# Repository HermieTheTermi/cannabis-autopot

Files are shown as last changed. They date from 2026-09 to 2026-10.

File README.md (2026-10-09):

# Smart Grow Topf

Automatisch bewässernder Topf für eine Cannabis-Pflanze, gesteuert über ein **ESP32-C6-Modul direkt auf der eigenen PCB** (eigener 2S-Lader, eigene 5-V-/3,3-V-Wandler), Akkubetrieb. **Eigenes Projekt** (unabhängig vom GrowTower).

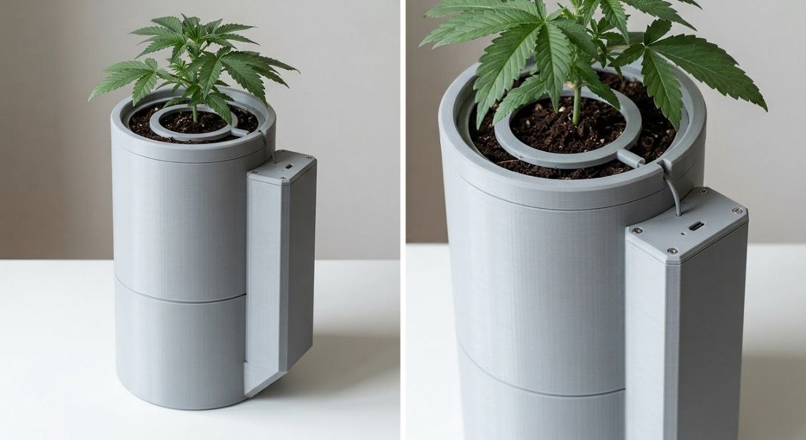
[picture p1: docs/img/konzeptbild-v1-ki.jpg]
Smart Grow Topf – KI-Konzeptbild im Stand V1


*KI-generiertes Konzeptbild (Prompts: [`docs/04_bildkonzepte-prompts.md`](docs/04_bildkonzepte-prompts.md)) — zeigt Wulst mit Deckel und USB-C, Verteilerring auf dem Substrat, Kragen. Keine CAD-Ableitung: verbindliche Maße stehen in [`docs/02_architektur-und-geometrie.md`](docs/02_architektur-und-geometrie.md).*

## Konzept (Top-Drip mit Rücklauf)

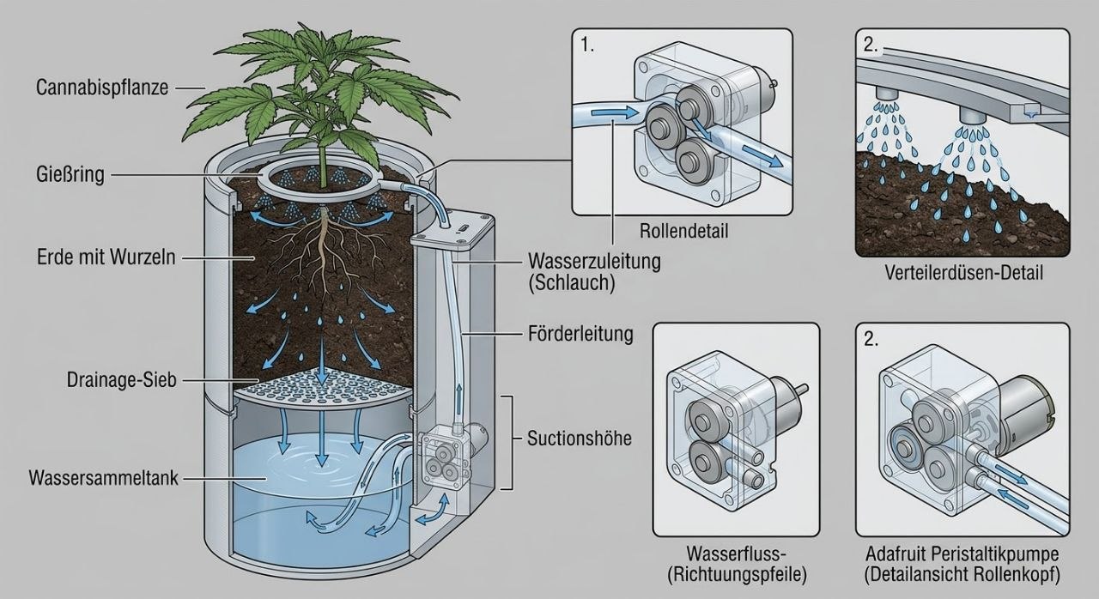
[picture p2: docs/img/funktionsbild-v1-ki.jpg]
Funktionsbild Smart Grow Topf – Weg des Wassers im Schnitt


*KI-generiertes Funktionsbild (Prompt 3 aus [`docs/04_bildkonzepte-prompts.md`](docs/04_bildkonzepte-prompts.md)) — Weg des Wassers: Peristaltikpumpe in der Wulst → Druckleitung über den Kragen → Gießring → Tropfen ins Substrat → Drainage-Sieb → zurück in den Sammeltank. Bild und Beschriftung sind KI-generiert und nicht maßhaltig. Was im Bild fehlt: der kapazitive Sensor (bei r ≈ 55 mm, Messebene 75 mm tief) und die 25 mm Blähton-Drainageschicht über dem Sieb; „Suctionshöhe" ist ein KI-Sprachfehler (gemeint: Saughöhe). Verbindlich bleibt [`docs/02_architektur-und-geometrie.md`](docs/02_architektur-und-geometrie.md).*

```
        Verteilerring (3D-Druck)          ← Wasser von oben
   ┌──────────────────────────────┐
   │  ERDE / SUBSTRAT             │   Ø127 innen × 150 mm (≈1,6 L)
   │  ⊗ kapazitiver Sensor        │   Messebene 75 mm = halbe Topfhöhe
   │  ▒▒ Blähton 25 mm ▒▒         │   Dränage + Partikelfilter
   └──────────────┬───────────────┘
        Luftspalt 30 mm (Gießfüße)
   ┌──────────────┴───────────────┐
   │  WASSERTANK 1,0 L            │   Ø134 innen, max. 71 mm Wasserstand
   └──────────────────────────────┘
        Wulst seitlich: Pumpe, PCB (ESP32-C6-Modul), Akku, Schlauch-/Kabelkanal
```

**Gesamthöhe 278 mm**, Grundriss Ø 140 mm (mit Wulst ≈ 180 mm breit).

**Regelkreis:**
1. Kapazitiver Sensor (analog, **invertiert**: trocken = hoher ADC) misst die Substratfeuchte.
2. Zu trocken → **Pumpe EIN** (Peristaltik, Wasser von oben auf den Verteilerring).
3. Überschuss läuft durchs Substrat und zurück in den Tank.
4. **10–20 min** später erneut messen: ADC gefallen → ok. ADC nicht gefallen → **Tank leer / Pumpe verstopft** → Telegram-Alarm.

## Warum dieses Design
- **Peristaltik:** Medium bleibt im Schlauch, kommt nie mit der Pumpenmechanik in Kontakt → sauber, kleine Mengen, akkutauglich, selbstansaugend.
- **Top-Drip:** gezielte Dosierung von oben, kein dauerhaft wassergesättigter Topfboden (Luftspalt), Wurzeln bleiben belüftet.
- **Kapazitiver Sensor:** korrosionsfrei, analog direkt am ADC, Messebene in der Wurzelzone.
- **Wulst statt Innenraum:** Elektronik komplett über dem Wasserstand, Sensor/Kabel/Schlauch sauber geführt.

## Projektstruktur
```
cannabis-autopot/
├── README.md
├── docs/
│   ├── 01_anforderungen.md              ← Festlegungen des Users
│   ├── 02_architektur-und-geometrie.md  ← verbindliche Maße (CAD/PCB-Grundlage)
│   ├── 04_bildkonzepte-prompts.md       ← KI-Image-Prompts (+ generierte .txt)
│   ├── 13_bildprompts-endstand.md       ← 3 deutsche Prompts für den fertigen Topf (inkl. Sprudler)
│   ├── 14_platinengroesse.md            ← Bauteilfläche + Boardgrößen-Rechnung (54 mm / frei)
│   └── img/                             ← KI-Konzeptbilder
├── scripts/
│   ├── check_netlist.py                 ← Lint der Netzliste (exit 0 vor dem Layout nötig)
│   ├── bauteilflaeche.py                ← Footprint-Flächen + Platinengröße (EasyEDA-API)
│   └── check_bom_consistency.py         ← Querabgleich Schaltplan ↔ JLCPCB-BOM
├── hardware/
│   ├── design/                          ← Schaltplan als Python-Modell: 29 Prüfungen + Simulationen
│   │   └── MUTATIONSTEST.md             ← Nachweis, dass jede Prüfung bei Fehlern anschlägt
│   ├── bom_entscheidung.md              ← BESTELLGRUNDLAGE: Bauteile, Preise, Links
│   ├── schaltplan_v1.md                 ← VERBINDUNGSVORGABE: Netze, Werte, Pinbelegungen
│   ├── schaltplan_v1_netzliste.csv      ← dieselben Verbindungen maschinenlesbar (Netz, Bauteil, Pin)
│   ├── pcba_bom_jlc.csv                 ← BOM im JLCPCB-Upload-Format (LCSC-Codes)
│   ├── pcba_verfuegbarkeit_jlc.md       ← JLC-Verfügbarkeitsprüfung je Position
│   └── hardware_auswahl_bom.md          ← Recherche-/Ideenebene (nicht Bestellgrundlage)
├── research/
│   ├── bom-check/                       ← aktueller Preis-/Verfügbarkeitscheck je Bauteilgruppe
│   ├── kapazitiver-bodenfeuchtesensor-esp32-recherche.md
│   ├── smart-grow-topf_pumpe-bewaesserung.md
│   ├── smart-grow-topf-esp32-firmware-konzept.md
│   ├── markt-konzept-recherche.md
│   ├── markt-vergleich-2026-09.md        ← „Gibt es das schon zu kaufen?“ (17.09.2026)
│   └── fertige-platinen/                 ← „Fertige Platine statt Eigenentwicklung?“ (09.10.2026)
│       ├── 00_verdikt.md                 ← Ergebnis: kein Board deckt alles, Modulweg als Rückfall
│       ├── 01_3d-drucker-mainboards.md   · 02_esp32-boards-akku.md
│       └── 03_power-management-2s.md     · 04_bewaesserungs-controller.md
│   └── bench-board/                      ← Entwicklungs-Board für den Labortisch (09.10.2026)
│       ├── 00_empfehlung.md              ← FireBeetle 2 ESP32-C6 (9,95 €) als Empfehlung + Einkaufsliste
│       ├── 01_steckbaukasten-grove-gravity.md · 02_io-boards-schraubklemmen.md
│       └── 03_mcu-dev-boards-zubehoer.md
└── cad/                                 ← parametrisches Gehäuse-CAD (build123d/Python)
    ├── params.py · lib.py                 ← alle Maße + Helfer
    ├── parts/*.py                         ← ein Modul je Druckteil (build/check)
    ├── assembly.py                        ← Baugruppe über RigidJoints
    └── export_all.py                      ← baut, prüft, exportiert STL + STEP
```

## Status
- [x] Projektordner + Anforderungen + 4 Recherchen (10.09.2026)
- [x] **Entscheidungen 11.09.2026:** Topf Ø140×150 (Erde) + 1 L Tank darunter · ESP32-C6-MINI-1 auf eigener PCB · Wulst mit Kanal · Top-Drip-Ring · Sensor von oben · Telegram final · nur Wasser
- [x] **Höhen-/Volumenberechnung** → Gesamthöhe 278 mm, Tank 1,0 L, Erdvolumen 1,9 L (`docs/02_...`)
- [x] **BOM-Entscheidung** (11.09.2026, Pumpentausch 14.09.2026): ESP32-C6-MINI-1 ≈ 3,60 € · Peristaltikpumpe **CONQUERALL DC 5 V** (Amazon `B0DHVMZ27Y`, ≤150 ml/min, 3 × 5 mm Schlauch) **11,99 €** statt 31,94 € OEM · Sensor v1.2 4,99 € · EFASO-Akku 14,90 € → **≈ 47–49 €** gesamt inkl. Schlauch und Passiven (+ ~28 € JLCPCB-Handling) (`hardware/bom_entscheidung.md`)
- [x] **Versorgung festgelegt (Revision „2S-Umbau\", 16.09.2026):** **2S-Pack 6,0–8,4 V** an J1, **3-polig (B− / Mittelabgriff / B+)** — **Zellschutz (HY2120) und Balancing (IP2326) sitzen auf unserer Platine** · Lader **IP2326** (2S-Boost-Lader aus 5 V USB, 8,4 V / 0,90 A) · **U_BUCK5 SY8113B** → **+5V (5,10 V)** für beide Pumpen und den neuen 5-V-Ausgang J17 · **U_BUCK3 AP63203** → **+3V3 (3,31 V)** für die Logik · Wächter **TPS3839G33** (Auslösung bei 6,16 V Pack). Ersetzt 1S-Akku, MCP73831, ME6211, MAX809 und den MT3608-Boost. ⚠️ **Offen:** der 3-A-Pumpenanlauf liegt zwar am Nennstrom des 5-V-Bucks, aber nur **0,57 A unter dem Isat (4,0 A)** der 4,7-µH-Induktivität → **PWM-Softstart weiter empfohlen**, Messauftrag in `docs/11_review-2s-umbau.md` §8 und `hardware/schaltplan_v1.md` §6.7
- [x] **PCBA geprüft (16.09.2026):** alle Bauteile bei JLCPCB verfügbar (LCSC-Codes in `hardware/pcba_bom_jlc.csv`; **109 bestückte Refs**, davon **17 Extended-Positionen ≈ 51 USD Handling** — `hardware/pcba_verfuegbarkeit_jlc.md` §1b)
- [x] **Sauerstoffpumpe + 5-V-Boost** (15.09.2026): **zweiter** Pumpenpfad — **Q3** (AO3400A) mit
      **R33/R34**, Freilauf **D7**, UV-Klemmzweig **D8**, Stecker **J16** (JST-XH 2P aufrecht, gleicher
      Typ wie J4) an **IO22** (vorher Reserve **J14** ⛔ entfällt). Damit **beide** Pumpen 5 V bekommen,
      erzeugt **U8 MT3608** mit **L1 22 µH**, **D6 SS34**, **C17/C18 22 µF**, **R31 75 kΩ/R32 10 kΩ**
      eine geregelte **+5-V-Schiene (5,10 V)** aus VBAT; J4 Pin 1 und D1 liegen jetzt an **+5V**.
      ⚠️ Zwei Folgepflichten: **PWM-Softstart jetzt Pflicht** (der Boost liefert den 3-A-Anlauf nicht —
      22 µF ≈ 7 µs) und **O2-Pumpe nicht dauerhaft** (1500-mAh-Zelle wäre in ~2,5 h leer).
      Rechnungen + offene Punkte (Platz!, Einbauort außerhalb) in `hardware/schaltplan_v1.md` §10
- [x] **Sauerstoffpumpe ausgewählt** (15.09.2026): **Mini USB Aquarium-Luftpumpe mit Luftstein**,
      Amazon **`B0FXB5BMTT`, 8,48 €** — **5 V USB**, ~1 W (**0,20 A**; aus der Zelle ≈ 0,32 A),
      < 35 dB, für 10–40 L, **Lieferumfang: Pumpe + 1,15 m Silikonschlauch + Luftsprudler**.
      Pumpe am **5-V-Boost** also unkritisch (Boost kann 1 A); Anschluss: USB-Stecker ab, rot/schwarz
      auf **JST-XH 2P (J16)**; Rückschlagventil in die Luftleitung; **außerhalb** des Topfs montieren
      (Membranpumpe braucht Frischluft). Alternativen: `B093GPMT1Z` (9,99 €, 210 L/h),
      `B0B82JX6Z4` (7,29 €, regelbar). Vergleichstabelle + Strom-/Laufzeitrechnung:
      `hardware/bom_entscheidung.md` §8
- [x] **Stecker auf „nach oben" umgestellt** (15.09.2026): J1/J2/J4 von gewinkelt (Side-Entry) auf
      **aufrecht (Top-Entry)** — neue LCSC-Codes `C160352` (Akku PH, SMD), `C493416` (Sensor XH-3P),
      `C158012` (Pumpe XH-2P); vorher `C54582899`/`C157928`/`C157931`. Die aufrechten Typen haben
      deutlich mehr Lager (u. a. J4: 203.889 statt 2). Elektrik unverändert (**Pin-Diff = 0, 50 Netze**),
      PCB per `import-changes` als **„Modify Footprint"** aktualisiert (80 Bauteile, **Platzierung erhalten**)
- [x] **Schaltplan V1 + Netzliste** (`hardware/schaltplan_v1.md`, `..._netzliste.csv`, **68 Netze / 115 Bauteile / 314 Verbindungen / 109 bestückte Positionen**)
- [x] **Design als Python-Modell + Prüfungen** (`hardware/design/`): **29** Design-Regelprüfungen gegen die
      Datenblattgrenzen, 6 Simulationsgruppen, Mutationsabdeckung vollständig (`hardware/design/MUTATIONSTEST.md`)
- [x] **Taster + 3 LEDs** (11.09.2026): externer Nachfüll-Taster an IO6 (weckt aus dem Deep-Sleep), nur
      2 Lötpads auf der Platine · **D5 rot = Tank leer** (IO7, R_TANK 1 kΩ, Firmware blinkt) ·
      **D2 grün = Status** (IO14, C2297, R4 **220 Ω** — grün hat Vf 2,85 V, am 3,3-V-Rail bleiben nur 0,45 V
      Reserve) · D_LEDCHG rot = Ladestatus. Neue Positionen sind **basic** (kein Extended-Aufpreis)
- [x] **Lichtsensor extern + Licht-Gate** (13.09.2026): Bewässerung nur in der Dunkelphase.
      Stecker **J7** (seit 14.09.2026 2,54-mm-Stiftleiste) mit **R_LIGHT 10 kΩ** (offener Stecker
      ⇒ 0 V ⇒ „dunkel", Bewässerung bleibt erlaubt) · **R_LIGHT_S 1 kΩ** + **C_LIGHT 100 nF** am
      ADC · Sensor an **SENSOR_PWR** (geschaltet, keine Standby-Verschlechterung) · ADC auf
      **IO4 (ADC1_CH4)**. Firmware-Fail-safe inkl. Zeitfenster-Fallback und Telegram-Alarm.
      **Pin-Korrektur:** IO4/IO5 sind keine boot-kritischen Strapping-Pins (nur GPIO8/9/15).
- [x] **Pinordnung GND–VCC–SIG** (13.09.2026): alle 3-poligen Stecker auf
      1 = GND · **2 = VCC** · 3 = Signal (nur der mittlere Pin ist gegen Umdrehen invariant — ein
      verkehrt gesteckter Stecker kann so **nie** 3,3 V auf einen MCU-Pin legen). J8 (I²C 4-pol)
      als **GND–VCC_EXT–SDA–SCL**.
- [x] **GPIO-Erweiterung auf 2,54-mm-Stiftleisten** (14.09.2026): alle freien GPIOs + I²C als
      **Stiftleisten (male, gerade)** für Dupont-Buchsen — **je Signal ein eigener 3-pol Stecker**
      (**J9–J15**: IO5/IO15/IO16/IO17/IO21/IO22/IO23), I²C als 4-pol **J8**, Lichtsensor **J7** jetzt
      ebenfalls Stiftleiste. **1 kΩ in Reihe in jeder Signalleitung**. Erweiterungsversorgung
      **VCC_EXT** über **P-Kanal-Load-Switch Q2 (AO3401A)**: Gate über 47 kΩ auf +3V3 ⇒ **aus beim
      Reset** (Fail-safe). **I²C-Pull-ups an VCC_EXT** (kein Busstrom im Aus-Zustand). **C_SPARE**
      100 nF am Reserve-ADC. Offline-Generatoren: 80 Bauteile / 50 Netze / 233 Verbindungen,
      `check_ir_netlist.py` 0 Abweichungen; Live-Neuaufbau des EasyEDA-Blatts steht aus.
- [x] **Gehäuse-CAD parametrisch in build123d** (`cad/`, 14.09.2026): 8 Druckteile + Baugruppe, alle Teile gegen die OpenSCAD-Vorlage geprüft (±0,4 % Volumen, bbox ≤ 0,04 mm), Druckteile als STL + STEP exportierbar
- [x] **Marktvergleich (17.09.2026):** kein Fertigprodukt deckt das Gesamtpaket ab — nächster Verwandter
      **LazyLeaf** (60 € UVP, Akku+Pumpe+1,1 l Tank, aber kein Feuchte-Sensor, kein WLAN), dazu Ivy/Tuya,
      Botanium, AutoPot/Blumat, AquaBloom, LetPot sowie die Grow-Kabinen (Vivosun 540 $, Hey Abby 700 $);
      Einordnung + Quellen in `research/markt-vergleich-2026-09.md`
- [x] **Marktrecherche „Fertige Platine" (09.10.2026):** Kein käufliches Board erfüllt die Anforderungsliste —
      3D-Drucker-Mainboards scheitern an Akkuladung/Deep-Sleep/Größe (bester: MKS TinyBee, 26,09 €), ESP32-Dev-Boards
      am 2S-Laden **und** an 5 V aus dem Akku (bester: FireBeetle 2 ESP32-C6, 6,30–9,95 €), Power-Manager an 2S
      (Waveshare SPM D: 5 V/3 A, aber nur 1S), Grow-Controller an Akku/Dosierpumpe/Lichtgate (DROPLET $87, z. Z.
      ausverkauft). **Rückfallweg dokumentiert:** HX-2S-JH20 (2,22 € netto, IC HY2120-CB + Balancer, 4,28 V/2,9 V
      je Zelle) + Type-C-2S-Boost-Lader + MINI560 — Eigenplatine bleibt günstiger und flacher. Wächter 6,16 V,
      µA-Aus-Schalter und 3-A-Anlaufpufferung gibt es als Fertigmodul **nicht** (`research/fertige-platinen/`)
- [x] **Entwicklungs-Board ausgewählt (09.10.2026):** Für den Labortisch (Größe/MCU egal) **FireBeetle 2 ESP32-C6**
      (ESP32-C6 = MCU der Endplatine, 7× ADC, 1S-Lader, 15–16,5 µA Sleep) **9,95 € Eckstein** — oder
      ESP32-C6-DevKitC-1 **11,95 € Reichelt** (mehr Pins, kein Lader). Alternativen: **KinCony KC868-A6**
      ($50, Schraubklemmen, 4× Analog 0–5 V, 6 Relais, ESPHome-Support, aber nur ~2 freie GPIOs, Relais = kein
      Softstart) · **MKS TinyBee** 29,99 € (MOSFET-Ausgänge, aber **nur Software-PWM** — Heiz-/Lüfterausgänge
      hängen am I²C-Expander; freie ADC1-Pins IO32/33/34/35/36/39) · XIAO ESP32-C6 7,49 € + Grove-Shield
      (BerryBase z. Zt. nicht lieferbar). Kein Board liefert 2S-Laden, 6,16-V-Wächter oder µA-Schlaf
      (`research/bench-board/00_empfehlung.md`)
- [ ] Firmware (State-Machine)

## Nächste Schritte
1. BOM finalisieren (Preise, Links, Verfügbarkeit) → `research/bom-check/`
2. Gehäuse-CAD (build123d, `cad/`) aus `docs/02_architektur-und-geometrie.md` — fertig, Teile drucken
3. PCB: ESP32-C6-Modul, IP2326-2S-Lader, SY8113B-Buck (5 V), AP63203-Buck (3,3 V), TPS3839-Wächter, MOSFET-Treiber, Sensor-ADC, USB-C, Taster-Lötpads, 3 LEDs — Netzliste `hardware/schaltplan_v1_netzliste.csv`
4. Firmware: State-Machine, Kalibrierroutine, Telegram-Alarm

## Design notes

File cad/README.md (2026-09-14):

# Gehäuse-CAD (build123d) — Smart Grow Topf V1

Parametrisches Modell in **Python/build123d** (ersetzt das frühere OpenSCAD-Modell in `case/`,
das am 14.09.2026 abgelöst wurde; die SCAD-Quellen liegen weiter in der Git-Historie).
Alle Maße stehen in **`params.py`** — nichts in den Bauteilen hart verdrahten.

## Aufbau

| Datei | Inhalt |
|---|---|
| `params.py` | alle Maße, benannt (Geometrie-Wahrheit: `../docs/02_architektur-und-geometrie.md`) |
| `lib.py` | gemeinsame Helfer: `rrect`, `hole_grid`, Wulst-Grundriss, Stutzenachse, Zylinderkette, Sonden-Messung |
| `parts/shell_upper.py` | Aussenschale oben (Wulst + Kragen + 47 LST-Ankerlöcher) |
| `parts/shell_lower.py` | Aussenschale unten (Wassertank + Einfüllstutzen + Steckzapfen) |
| `parts/inner_pot.py` | Innentopf mit Gießfüßen, Drainage und Schlauchdurchlass |
| `parts/grid.py` | Auflagerost / Blähton-Rückhalt |
| `parts/distribution_ring.py` | Verteilerring (Top-Drip) |
| `parts/wulst_lid.py` | Wulstdeckel (Dichtungsnut, USB-C, LED) |
| `parts/cover.py` | optionale Substrat-Abdeckung |
| `parts/fill_cap.py` | Kappe auf dem Einfüllstutzen (Klemmsitz, Lüftungsloch) |
| `assembly.py` | Baugruppe: alle Teile über benannte `RigidJoint`s + `connect_to()` verbunden |
| `export_all.py` | baut, prüft und exportiert **alle** Bauteile (STL + STEP) |

Konvention je Bauteil: `NAME`, `build()` → `Part`, `check(part)` → Asserts + Kennzahlen.
`export_all.py` findet die Module selbst (`parts/*.py`) und bricht mit Exit-Code 1 ab, wenn
eine Prüfung nicht hält.

## Bauen und prüfen

```bash
cd ~/Projekte/cannabis-autopot
/Users/manuel/.venvs/cad/bin/python cad/export_all.py   # alle Teile: prüfen + cad/export/*.stl + *.step
/Users/manuel/.venvs/cad/bin/python cad/assembly.py     # Baugruppe + Interferenzprüfung
f3d --output=/tmp/teil.png --resolution=1100,800 cad/export/teil.stl   # Ansicht erzeugen
```

Explosionsansicht aller 8 Druckteile: `cad/exploded.py` schreibt `cad/export/exploded.step`/`.stl`, gerendert z. B. mit `f3d --output=/tmp/exploded.png --resolution=1500,1100 --camera-position=-850,-1130,1150 --camera-focal-point=0,0,380 --camera-view-up=0,0,1 cad/export/exploded.stl`.

`cad/export/` ist Build-Artefakt und per `.gitignore` ausgenommen — versioniert werden nur die
Python-Quellen.

## Bauteile, Drucklage, Bauraum (220 × 220 × 250 mm)

| Teil | Bauraum (X × Y × Z) | passt |
|---|---|---|
| shell_upper | 144 × 184 × 188 | ✅ (Drucklage: um 90 mm nach unten verschoben, Kragen oben) |
| shell_lower | 140 × 140 × 96 | ✅ |
| inner_pot | 132 × 132 × 180 | ✅ (Gießfüße ragen nach unten, z −30…150) |
| distribution_ring | 105 × 113 × 16 (Stutzen +Y) | ✅ |
| grid | 132 × 132 × 4 | ✅ |
| wulst_lid | 60 × 160 × 4 | ✅ |
| cover | 136 × 136 × 3 | ✅ |
| fill_cap | 32 × 32 × 8 | ✅ |

Verbindung der beiden Schalensegmente: Steckzapfen Ø 136 / Sockel Ø 137,2 an der Trennebene
**z = 90 mm** (0,6 mm radial Spiel), Dichtung optional mit Silikon.

## Druck

- **Schichthöhe** 0,20 mm · **Wandzahl** 3 (≈ 1,2 mm) · Top/Bottom ≥ 4.
- Material PLA oder PETG. **Keine Stützstrukturen nötig** — Wulstboden und Einfüllstutzen sind
  als 45°-Fasen ausgeführt, alles andere steht auf ebenen Flächen.
- Ausrichtung: Schalen und Innentopf **stehend** (Kragen/Wulst bzw. Füße nach unten), Rost,
  Ring, Deckel, Abdeckung und Kappe **flach** (Kappe mit der Öffnung nach oben).
- Die LST-Löcher im Kragen sind Ø 2,2 mm gezeichnet → gedruckt bleiben ca. 2,0 mm (nimmt
  1,5–2 mm Schnur). Sie sind im Ausdruck nicht zuzustopfen notwendig; bei Bedarf mit einer
  Nadel nachfädeln.

## Montage

1. `shell_lower` aufstellen, `grid` auf den Auflagering (z = 79–82) einlegen.
2. `shell_upper` auf den Zapfen stecken (ggf. Silikon-Dichtnaht).
3. Saugschlauch vom Wulst durch den 6 × 6-Kanal in den Tank führen, Filtergewicht anhängen;
   Pumpe anschließen; Druckschlauch durch die Ø-6,5-Bohrung oben nach außen zum Verteilerring.
4. `inner_pot` (Füße nach unten auf den Rost) einsetzen, 25 mm Blähton als Drainage, darüber
   Substrat.
5. `distribution_ring` auf die Substratoberfläche legen (Stutzen zeigt nach **+Y** zur Wulst),
   Druckschlauch aufstecken — **nicht** durch den Sensorkabel-Ausschnitt am Kragen führen.
6. Feuchtesensor bei r ≈ 55 mm auf 75 mm Tiefe stecken, Kabel über die Kragenaussparung in den
   Ø-4,5-Kabelkanal führen (Tropfschlaufe vor dem Eintritt).
7. Elektronik einlegen, `wulst_lid` mit Dichtung aufsetzen, mit 4 × M2,5 verschrauben.
8. `fill_cap` auf den Mund des Einfüllstutzens drücken (Klemmsitz, Lüftungsloch bleibt frei).
9. `cover` optional auf den Kragen legen.

**Wasser nachfüllen:** Kappe abziehen, durch den 45°-Stutzen auf der Wulst-Gegenseite (−Y)
einfüllen (Trichter empfohlen). Kein Abnehmen der oberen Schale mehr nötig. Läuft Wasser aus dem
Mund zurück, ist der Tank voll (≈ 1,07 L, Konstruktionswert 1,0 L bei 71 mm = max. Wasserstand).

**LST (Low-Stress-Training):** Fäden durch die Löcher im Kragen fädeln (2 Reihen, versetzt,
47 Löcher, Ø 2,2 mm) — von außen erreichbar, innen öffnen sie sich in den Luftraum über dem
Topfrand, also nicht im Substrat. **Vor dem Abnehmen der oberen Schale die Fäden lösen.**

## Annahmen / Abweichungen gegenüber der SCAD-Vorlage

- **LST-Löcher korrigiert:** In der SCAD-Vorlage war die Freihaltung am Sensorkabel-Ausschnitt um
  90° verdreht (sie sparte bei 180° aus, gemessen: 44 Löcher). Jetzt 24 Positionen je Reihe,
  zweite Reihe um 7,5° versetzt, ausgespart wird nur, was im Kragenausschnitt (+Y) läge →
  **23 + 24 = 47 Löcher**.
- Der Einfüllstutzen ist gegenüber dem SCAD-Stand 4 mm länger (`fill_len` 22 statt 18) und die
  Kappe flacher (8 mm, Nut 4 mm), weil der Kappenrand sonst an der Tankwand anlag (im SCAD
  224 mm³ Überlappung, jetzt nur noch der Klemmsitz).
- Zwei Überlappungen in der Baugruppe sind **von der SCAD-Vorlage geerbt** und bewusst nicht
  geändert: die Wulst-Tropfkante berührt die Innentopfwand (≈ 14,5 mm³) und der Rost berührt
  den Kappenrand (≈ 0,1 mm³). Beide sind in der Fertigung unkritisch (Toleranz/Spiel).
- Die Ansichtsdateien der Vorlage (`outer_shell`, `case`-Gesamtlayout) sind **nicht** portiert;
  die Übersicht liefert `assembly.py` (montierte Baugruppe als STEP/STL).

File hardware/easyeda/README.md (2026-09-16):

# SmartGrowTopf V1 — Schaltplan (EasyEDA Pro) als Code erzeugt

Dieses Verzeichnis enthält den **kompletten, reproduzierbaren Bau des Schaltplans** für den
Autopot "SmartGrowTopf_V1" in EasyEDA Pro — gebaut mit der `easyeda-agent` CLI in der Reihenfolge
des Design-Flows S0–S6 (`docs/09_easyeda-schaltplan-uebergabe.md`). Quelle der Schaltung ist die
Handnetzliste `../schaltplan_v1_netzliste.csv`.

> **Stand 15.09.2026 — zweiter Live-Neuaufbau (Review-Revision eingespielt):** Die Seite wurde erneut
> **von Grund auf** gebaut, jetzt mit der überarbeiteten Schaltung: **96 Bauteile, 56 Netze,
> 268 Verbindungen, 13 Module, 13 Rahmen**. Live: `sch clear` (93 Bauteile/262 Drähte/13 Rahmen),
> `place_all.sh` **96/96 FAIL=0**, 13 Rahmen + 13 Titel (`clear --dry-run`: `rectangles: 13`, `texts: 13`),
> 13 Gruppen, `autoconnect` je Modul. **7 Verbindungen** mussten wegen transienter
> `connector did not respond`-Timeouts per Retry-Spec nachgezogen werden (C10:2, C14:2, C15:2, C16:2,
> Q1:2, J2:1, R16:1) — danach **Pin-für-Pin-Diff gegen die Ziel-IR: 0 Abweichungen** (268 Pins, 56 Netze).
> 8 NC-Marker gesetzt (J1:3/4, J5:B8/A8, SW1:3/4, SW2:3/4). `sch gate`: **layout-lint pass (0/0, 0 out-of-sheet)**,
> `check` pass, `bridge-check` pass (**0 Waisen**, 268 Drähte), `drc` pass; `clusters` meldet 1 Überlappung
> und 1 Bauteil knapp außerhalb (Layout — wird vom Nutzer selbst gemacht). Gespeichert.
> Blattbild: `.easyeda/artifacts/20260915-093824-schematic_export-b8231b42.png`.
> **Neu gegenüber dem ersten Aufbau:** R35/R36 (10 kΩ) in den Klemmzweigen, R37 (47 kΩ) als
> Boost-EN-Pull-up, Gate-Serien R1/R33 auf 1 kΩ, I²C-Pull-ups R19/R20 auf 4,7 kΩ.
>
> ⚠️ **Falle beim Live-Lauf:** Ist kein EasyEDA-Fenster verbunden (`windows: []`), schlägt `sch clear`
> **still** fehl und `place_all.sh` läuft gegen den alten Bestand → nur **einzelne FAILs** (Designator-
> Kollisionen), der Rest sieht „erfolgreich" aus. Vor jedem Lauf `easyeda daemon health` prüfen und
> `easyeda doc open <uuid> --project <name>` fahren.
>
> **Stand 15.09.2026 (Sauerstoffpumpe + 5-V-Boost, Neuaufbau der Seite):** Die Generatorkette läuft
> wieder vollständig und die Seite wurde **von Grund auf neu gebaut** (kein Flicken, kein manuelles
> Umplatzieren): **93 Bauteile, 54 Netze, 262 Verbindungen, 13 Modulgruppen, 13 Modulrahmen**.
> `check_ir_netlist.py` = **0 Abweichungen**; `plan_layout.py` = kein Planungsproblem (Blattnutzung
> **78,7 %**); `check_plan_fit.py` = **Exit 0** (0 überlappende Rahmen, kleinster Volumenabstand 25);
> `build_autoconnect.py` = **13 Spec-Dateien mit 261 Verbindungen**.
> Live: **93 Bauteile platziert (0 FAIL)**, 13 Rahmen + 13 Titel gezeichnet (die Rücklese-Prüfung
> meldet `verified:false` wegen des bekannten Vorzeichenfehlers — `sch clear --dry-run` beweist
> `rectangles: 13, texts: 13`), 13 Gruppen angelegt, **261 von 262 Pins verdrahtet**,
> **Pin-für-Pin-Diff gegen die Ziel-IR = 0 Abweichungen**, `sch gate`: `layout-lint` pass (0/0),
> `check` pass, `bridge-check` pass (**0 Waisen**), `drc` pass — **einziger Restpunkt** ist ein
> Cluster-Overlap `D7 ↔ D8` (22 × 6 Einheiten, reine Lesbarkeit) im Pumpenblock.
> Blattbild: `.easyeda/artifacts/20260915-090028-schematic_export-63b30385.png`.
>
> **Neu inhaltlich:** zweiter, baugleicher Pumpenpfad für die **Sauerstoffpumpe** (`Q3`, `R33`, `R34`,
> `D7`, `D8`, `C20`, `J16`) an **IO22** — der Reserve-Stecker **J14** entfällt dafür — und ein
> **5-V-Boost** (`U8 MT3608`, `L1`, `D6`, `C17/C18` 22 µF, `C19` 100 nF, `R31/R32`) aus VBAT, damit
> **beide** Pumpen an **+5V** hängen. ⚠️ Folgepflichten: **PWM-Softstart zwingend** (der Boost liefert
> den 3-A-Anlauf nicht) und die Sauerstoffpumpe **nicht im Dauerbetrieb** (Akku in ~2,5 h leer).
> Details + Rechnungen: `../schaltplan_v1.md` §10.
>
> ⚠️ **Arbeitsweise (User-Vorgabe 15.09.2026):** Bei Schaltplan-Änderungen **immer** diese Kette
> benutzen — `sch clear` → `raw/place_all.sh` → Rahmen (je Rahmen eigene Datei!) → Gruppen →
> `autoconnect --spec raw/ac_<MODUL>.json` je Modul → NC-Marker → Pin-für-Pin-Diff → `gate`.
> **Nichts manuell nachrücken**, **keine Designatoren selbst vergeben** (das macht die Allokation in
> `raw/designator_changes.json`), **keine Rahmen/Gruppen vergessen**. Neue Bauteile gehören mit
> funktionalem Namen in `COMPS`/`modules.json`, ihre Pin-Tabellen als `raw/probe*.json`, ihre Volumen
> in `raw/measured_volumes_<datum>.json`.
>
> **Stand 14.09.2026 (GPIO-Erweiterung auf 2,54-mm-Stiftleisten):** Die Offline-Generatoren
> (`build_ir.py`, `plan_layout.py`, `build_autoconnect.py`, `netclass_spec.py`) wurden auf die
> erweiterte Netzliste gezogen: **80 Bauteile, 50 Netze, 233 Verbindungen, 12 Modulgruppen**;
> `check_ir_netlist.py` = **0 Abweichungen**; `plan_layout.py` packt jetzt mit den live
> gemessenen Bauteil-Volumen (`raw/measured_volumes_2026-09-14.json`, Koerper + Marker/Stiche)
> ohne Planungsproblem (`raw/frames.json` = **12 Rahmen**, Blattnutzung **71,1 %**);
> `check_plan_fit.py` = **Exit 0**; `raw/ac_ERWEITERUNG.json` wieder vorhanden.
> Der **Live-Bau in EasyEDA ist noch auf dem Rückbau-Stand** (58 Bauteile, 32 Netze, 171
> Verbindungen, 11 Modulgruppen, `sch gate` = pass) und muss vom Koordinator mit
> `sch clear → place → frames → autoconnect` auf den neuen Stand gezogen werden. Live-Nachweise
> des alten Stands: `s5/live_connectivity_2026-09-14.json`, `s5/FINAL_gate_2026-09-14.json`,
> Blattbild `../../out/schaltplan_2026-09-14.png` (+ `.svg`).
>
> **Erweiterung 14.09.2026:** Freie GPIOs + I²C als **2,54-mm-Stiftleisten** — **J8** (I²C 4-pol,
> GND–VCC_EXT–SDA–SCL), **J9–J15** (je 3-pol, GND–VCC–SIG), Lichtsensor **J7** ebenfalls
> Stiftleiste, **Q2 AO3401A** als Load-Switch für VCC_EXT, 1 kΩ in jeder Signalleitung,
> I²C-Pull-ups an VCC_EXT, `C_SPARE` am Reserve-ADC. Live-Device-Identitäten der drei neuen
> LCSC-Positionen am 14.09.2026 per `easyeda lib by-lcsc --include-device-identity` aufgelöst;
> das gemessene Library-Präfix der Stiftleisten ist **`H?`** (projektseitig bewusst als J-Refdes
> geführt, wie schon J2/J7 mit Präfix `CN?`).
>
> **Rückbau 14.09.2026:** Die GPIO-Erweiterung vom 13.09. (J8/J9/J10/Q2/TP7–TP11) war zwischen-
> zeitlich wieder entfernt und ist mit dieser Änderung in neuer Form (Stiftleisten) zurück.
>
> **Nachbesserung 13.09.2026 (Massepads):** Die frühere Sammelzeile `U1 1/2/11/14/36-53` in
> der Netzliste ist in Einzelzeilen aufgelöst. Das ESP32-C6-MINI-1-Symbol hat **keinen
> Bus-/Sammelpin** — alle 22 GND-Pads (1, 2, 11, 14, 36–53) haben live geprüfte eigene
> Koordinaten und werden einzeln verdrahtet. Die Zeile `EPAD (Pin 49)` ist als Kommentar
> erhalten (Pad 49 ist in 36–53 enthalten, kein Phantompin).
>
> **Historisch (11.09.2026):** Der erste eingecheckte Bau hatte 30 Netze und **keinen**
> Lichtsensor; die Zahlen in den Prüfberichten vom 11.09. beziehen sich darauf.

Stand des Offline-Aufbaus: **14.09.2026** · Tool: `easyeda-agent` 1.4.8 · Blatt: **A1 Querformat** (841 × 594 mm; 3304 × 2338 raw)

---

## Ergebnis (Offline-Generatoren, Stand 14.09.2026)

| Prüfung | Werkzeug | Stand |
|---|---|---|
| Bauteile / Netze | `raw/ir_report.txt` | **80 Bauteile, 50 Netze, 233 Verbindungen**, 16 NC-Pins, keine Probleme |
| Module | `raw/modules.json` | **12 Module** (USB, LADER, DEBUG, MCU, WAEChTER, LDO, AKKU, SENSOR, PUMPE, TASTER, LICHT, ERWEITERUNG) |
| Rahmen | `raw/frames.json` | **12 Rahmen** (11 bestehende + `frame-erweiterung`) |
| Netzlisten-Treue | `check_ir_netlist.py` (Pin-für-Pin gegen `raw/ir_numbered.json`) | **0 Abweichungen** (233 Verbindungen, 50 Netze) |
| Platzierung | `plan_layout.py` | kein Planungsproblem; 12 Blöcke aus den gemessenen Volumen gepackt, Blattnutzung 71,1 % (Volumen 15,2 %) |
| Platzierungs-Fit (offline) | `check_plan_fit.py` | **Exit 0** — 80 Volumen im Nutzbereich, kleinster Volumen-Abstand 25,00, kleinster Rahmen-Rand 150, 0 Blocküberlappungen |
| Autoconnect-Specs | `build_autoconnect.py` | **12** Spec-Dateien, `raw/ac_ERWEITERUNG.json` mit **54** Verbindungen |

**Live-Bau in EasyEDA (Stand 14.09.2026, Blatt A1 = 3304 × 2338):** 80 Bauteile, 50 Netze,
233 Verbindungen, pin-für-pin **0 Abweichungen** zur Netzliste, 12 Modulgruppen, 12 Modulrahmen,
NC-Marker auf allen 16 freien Pins. `sch gate` = **pass**; `sch gate --strict` = fail
(einziger Blocker: `missing-titleblock`, Host-Eigenheit). Nachweise:
`out/schaltplan_2026-09-14_A1.png` / `.svg`, `s5/live_connectivity_2026-09-14_A1.json`,
`s5/FINAL_gate_2026-09-14_A1.json`.

---

## Bekannte Restpunkte (rein kosmetisch)

1. **`missing-titleblock`** — die Prüfung sucht ein Titelblock-Feld namens `Drawed`; diese
   EasyEDA-Version kennt nur `Drawn`. Nicht behebbar, Host-Eigenheit. Der **einzige** Grund,
   warum `sch gate --strict` nicht grün ist (`sch gate` ohne `--strict` ist pass).
2. **Modulrahmen berühren sich teils** (z. B. LDO/DEBUG, TASTER/AKKU, USB/PUMPE) — erlaubt (nur
   Überlappung ist verboten), lässt aber keinen Zwischenraum für modulübergreifende Verdrahtung.
   Bei Bedarf später ein kleiner Zwischenabstand zwischen den Blöcken.
3. **Offline-Plan kennt nur die Fächer-Größe, nicht die -Richtung.** `plan_layout.py` rechnet je
   Bauteil die gemessenen Volumen (inkl. eigener Marker/Stiche) und 150 Einheiten Blockrand
   Reserve ein; ob der Autoconnect-Solver den Fächer live genau dorthin legt, entscheidet erst
   der Live-Lauf. Auf A2 ist genau daran `clusters` gescheitert (bis −92 out-of-sheet) — der
   Grund für den Wechsel auf A1.
4. **PCB** ist am 14.09.2026 neu aufgesetzt worden (nach dem Blatt-Neuaufbau): `pcb clear`
   (58 alte Bauteile weg, Blattkontur bleibt) + `pcb import-changes` → **80 Bauteile, 50 Netze,
   0 Leitungen**; Belege `s5/archiv/pcb_vor_neuaufbau_2026-09-14.json` (Zustand davor) und
   `s5/pcb_after_import_2026-09-14.json` (danach). Die Bauteile liegen als Streuung außerhalb der
   Blattkontur und sind **nicht** platziert/geroutet — Platzieren, Verdrahten und Routen macht der
   Nutzer selbst.

---

## Aufbau (Reihenfolge)

```bash
cd hardware/easyeda
export PATH="$HOME/.local/bin:$PATH"
P=4f6771a27edec75b          # Seiten-ID; Achtung: der Name der Seite ist KEIN gültiger --doc-Wert
G=(--project "SmartGrowTopf_V1" --doc $P)

# S0  Spezifikation (Board 38 mm, 2 Lagen, GND-Fläche unten) → s0_spec.json
# S1  Netzliste + Symbole → kanonische IR (Designator-Nummerierung offline nachgebildet)
python3 scripts/build_ir.py                                   # → raw/ir_draft.json, raw/ir_numbered.json,
                                                              #   raw/no_place.json  (32 Umbenennungen)
python3 scripts/check_ir_netlist.py                           # Pin-für-Pin: 0 Abweichungen
# S2  Module/Gruppen + Rahmen
python3 scripts/plan_layout.py                                # → raw/place_all.sh, raw/frames_*.json
python3 scripts/check_plan_fit.py                             # offline: Volumen/Ränder/Blöcke, Exit 0
bash raw/place_all.sh                                         # 80/80 platziert
easyeda "${G[@]}" sch zone-draw … ; easyeda "${G[@]}" sch frame apply …
# S3/S4  Verdrahtung je Modul (autoconnect statt lib-layout-Solver), inkl. 22 Einzel-GND-Pads
python3 scripts/build_autoconnect.py                          # → raw/ac_<MODUL>.json
easyeda "${G[@]}" sch autoconnect --spec raw/ac_USB.json --replace …
easyeda "${G[@]}" sch autoconnect --spec raw/ac_MCU.json --replace …   # U1 1,2,11,14,36–53 GND einzeln
# S5  Prüfen
easyeda "${G[@]}" sch layout-lint --json ; easyeda "${G[@]}" sch check --json
easyeda "${G[@]}" sch bridge-check --json ; easyeda "${G[@]}" sch drc --json
easyeda "${G[@]}" sch gate --json ; easyeda "${G[@]}" sch gate --strict --json
# S6  Sichern + Export
easyeda "${G[@]}" sch save
easyeda "${G[@]}" sch export-image --format png --out out/SmartGrowTopf_V1_A1_final.png
```

Die Papiergröße (A4 → A1) ist **nicht** über die CLI änderbar: Blatt im EasyEDA-Canvas anklicken →
rechtes Panel „Drawing" → Feld `Size`. Danach mit `sch sheet-geometry` gegenprüfen.

## Dateien

| Pfad | Inhalt |
|---|---|
| `scripts/build_ir.py` | Netzliste + Symbol-Pins → kanonische IR + Designator-Nummerierung |
| `scripts/check_ir_netlist.py` | Selbstkonsistenz IR ↔ Handnetzliste (Pin für Pin) |
| `scripts/plan_layout.py` | Modulblöcke, Platzierungsbefehle, Rahmen |
| `scripts/check_plan_fit.py` | Offline-Prüfer der Platzierung gegen die gemessenen Volumen |
| `scripts/build_autoconnect.py` | Autoconnect-Specs je Modul (12 Dateien) |
| `scripts/build_layout_input.py` | Eingabe für den Solver `sch lib-layout` (verworfen, s. u.) |
| `scripts/repair_pins.py` | Wiederherstellung der Verdrahtung nach dem Marker-Vorfall |
| `scripts/fix_overlaps_safe.py` | kosmetische Marker-Korrektur (nur `disconnect --flag-id`) |
| `scripts/netclass_spec.py` | Leiterbahnbreiten für die PCB-Phase (IPC-2221A) → `netclass_spec.json` |
| `scripts/pcb_widths.py` | Breiten auf der Platine prüfen/nachziehen (`--check`/`--apply`/`--route-plan`/`--selftest`) |
| `raw/` | IR (numeriert), Module, Symbole, Autoconnect-Specs, Platzierungsskript |
| `s1/` `s3/` `s4/` `s6/` | Zwischenstände (Seitenzustand, Verdrahtung, Titelblock) |
| `s5/FINAL_*` | **Abnahme-Belege** (gate, gate strict, check, bridge, drc, lint, read, Gruppen, Status) |
| `s5/b2_*` | Autoconnect-Läufe der finalen A1-Verdrahtung |
| `s5/archiv/` | alle Zwischenläufe (Zwischenprüfungen, verworfene Versuche) |
| `out/` | Bild-Exporte (PNG/SVG, A1) |

## Erfahrungen, die den Aufbau erklären

- **`sch autoconnect` statt `sch lib-layout`**: Der Layout-Solver platziert selbst und scheitert an
  den gemessenen Posen („cannot route direct net USB_DP … without crossing obstacles").
- **Kein Buspin am Modul**: das ESP32-C6-MINI-1-Symbol hat für die durchgehenden Massepads
  36–53 je eine eigene Pin-Nummer (live geprüft, keine Stapel-/Buspins). Die 18 Pads werden
  daher einzeln verdrahtet; ein Sammelpin existiert nicht.
- **Marker nie per `disconnect --pin` umhängen**: dabei wurden einmal 38 Pins auf das falsche Netz
  gezogen (VBAT an GND) — erkannt durch Pin-für-Pin-Vergleich, behoben mit `repair_pins.py`.
  Sichere Klinge ist `disconnect --flag-id` + `connect --pin`, mit Netzlisten-Prüfung nach jedem Schritt.
- **`sch clear` leert mehr als die Bauteile**: auch Gruppen, Rahmen und NC-Marken verschwinden.
- **Mehr Blattfläche entspannt die Optik**: auf A4 gab es 9 Cluster-Überlappungen und 15 aus dem
  Blatt ragende Marken — auf A1 sind es 0 bzw. 0.
- **`VDD33` bleibt unverbunden**: das offizielle ESP32-C6-MINI-1-Symbol hat genau einen 3V3-Pin;
  die VDD33-Pins sind modulintern verbunden. Die Netzliste bleibt unverändert.

## Nächster Schritt

PCB-Phase: `easyeda pcb import-changes` (Layout-Import aus dieser Seite), Stackup/Board aus
`s0_spec.json` (38 mm, 2 Lagen, Massefläche auf der Unterseite).
**Leiterbahnbreiten sind vorab festgelegt** (`netclass_spec.json`, Erklärung in
`docs/10_pcb-leiterbahnbreiten.md`): VBAT / PUMP_N / VBUS 0,5 mm, +3V3 0,4 mm, Signale
0,25 mm, Masse als Fläche. `PUMP_N` muss dabei explizit mit `pcb track --width 20`
gelegt werden — die Namensheuristik des Tools hält es für ein Signal.

---

## Stand 16.09.2026: Seite neu aufgebaut (2S + Akku-Schutz) — Ergebnis

Der komplette Neuaufbau über die Projektkette ist gelaufen und **pin-für-pin verifiziert**:

| Schritt | Werkzeug | Ergebnis |
|---|---|---|
| IR aus Netzliste | `build_ir.py` + `check_ir_netlist.py` | **124 Bauteile, 77 Netze, 351 Verbindungen, 0 Abweichungen** |
| Designator-Allokation | `easyeda sch designators allocate` | 79 Namen → Zahlen; **0 funktionale Designatoren** mehr; `prefixes.json` auf 53 Einträge (gemessene Präfixe: Stecker `CN?`, Stiftleisten `H?`) |
| Platzierung (offline) | `plan_layout.py` + `check_plan_fit.py` | 124 Bauteile, 14 Blöcke == 14 Module, Blattnutzung 91,0 %, **Fallback 0**, Fit OK |
| Platzierung (live) | `raw/place_all.sh` | **124 platziert, 0 FAIL** (66 s) |
| Rahmen/Gruppen | `sch frame apply` (je Rahmen eigene Datei) + `sch group create` | **14 Rahmen, 14 Gruppen** (Im Bild sichtbar; die Rücklese-Prüfung meldet weiter den bekannten Vorzeichenfehler) |
| Verdrahtung | `sch autoconnect --spec raw/ac_<MODUL>.json` | **351 von 351 Verbindungen**, 77 von 77 Netzen |
| NC-Marker | `sch no-connect` | 20 freie Pins markiert (J5 A8/B8, SW1/SW2 3/4, U1 4/7/21/32–35, U2 1/2/3/5/7/9/10) |
| Live-Abgleich | Pin-für-Pin gegen `raw/ir_numbered.json` | **0 fehlend, 0 falsches Netz, 0 überzählig** |
| Gate | `sch gate --json` | `layout-lint` pass, `check` pass, `bridge-check` pass (0 Waisen), `drc` pass; **`clusters` fail: 2 Überlappungen** (R40↔R41, U2↔L1) = reine Lesbarkeit, laut Projektregel Sache des Nutzers |
| Blattbild | `sch export-image` | `out/schaltplan_2026-09-16_2s_schutz.png` |

**Nebenbefunde, die Zeit gekostet haben (für den nächsten Lauf wichtig):**
1. **`pcb import-changes` überträgt nichts** — laut eigener CLI-Hilfe ist es ein **No-op für Bauteile, die
   über die API in den Schaltplan gekommen sind** (Issue #20). Unser Plan ist komplett so entstanden.
   Zusätzlich verweist das PCB-Dokument auf eine **veraltete Seiten-UUID** (`6118d8e393808567`) statt auf
   die aktuelle Seite `4f6771a27edec75b`.
2. **`pcb new-board` scheitert in diesem EasyEDA-Build** („createPcb returned nothing — SDK no-op").
3. Der dokumentierte Arbeitsweg ist daher **`pcb add-component` je Bauteil** (Fußabdruck + Verknüpfung
   zur Schaltplan-Zwilling + Pad-Netze). Die Daten dafür liegen bereit: `sch read` liefert je Ref
   `uniqueId`, Position und Pad→Netz, `raw/ir_numbered.json` die Device-Identität.
4. `--include-device-identity` in Kombination mit `--include-pins`/`--include-bbox` schlägt reproduzierbar
   fehl („connector did not respond") — die Pin-Tabellen wurden daher mit `--include-pins --include-bbox`
   gemessen und die Device-Identität über die Platzierungsliste zugeordnet
   (`raw/probe_2s_2026-09-16.json`).
5. In `plan_layout.py` stand `--doc P1` (Seitenname statt UUID) und `>/dev/null 2>&1` — die Platzierung
   schlug dadurch komplett still fehl, sichtbar nur als `FAIL <Ref>`. Behoben.

**Offen / nächster Schritt:** das PCB mit den 124 Bauteilen versorgen (siehe 1.–3.) — danach **stoppt**
die Arbeit hier, Platzieren und Routen macht der Nutzer selbst.

---

## Offen für den nächsten EasyEDA-Durchgang (Stand 16.09.2026)

Nach der Übernahme ins PCB hat ein externes Review mehrere Korrekturen ausgelöst, die **bisher nur
lokal** (Netzliste, Dokument, Stückliste) umgesetzt sind. Der Live-Bau in EasyEDA ist damit **nicht
mehr deckungsgleich** und muss nachgezogen werden:

| Änderung | Wirkung auf die Kette |
|---|---|
| `U_BUCK3` Pin 1 (FB) liegt **direkt auf `+3V3`** | Netz `FB_3V3` entfällt, `R_FB3_TOP`/`R_FB3_BOT` entfallen |
| Dioden-Klemmzweig entfernt | `D3`, `D8`, `R_CLAMP1`, `R_CLAMP2` und `KLAMP1`/`KLAMP2` entfallen |
| UV-Teiler | `R3a`/`R3b`: 200 kΩ → **51 kΩ** (gleiche Bauteile, neue Werte) |
| Sensor-Lastschalter | **neu `Q_SENS`** (AO3401A, `C15127`) + **`R_SENS_GATE`** 47 kΩ + Netz `EXT_SENS_EN` |
| Sicherung | **neu `F1`** (5 A träge, 2410, `C66503`) + Netz `PACK_PLUS` |
| Akku-NTC | **neu `J18`** (JST-XH-2P, `C158012`) + **`R_NTC_PAR`** 82 kΩ (`C17840`), Netz `NTC_CHG` |
| `R_CB` | Bauform 0805 → **1206** (0,25 W, `C17901`) |

**Arbeitsschritte beim nächsten Mal:** für die vier neuen bzw. geänderten Geräte
(`F1` Sicherung, `J18` XH-2P, `R_NTC_PAR` 82 kΩ, `Q_SENS` AO3401A) Geräte-UUIDs auflösen,
Pin-Tabellen per Probe-Platzierung messen, `raw/lcsc_map.json`/`prefixes.json` ergänzen, dann
`build_ir.py` → `plan_layout.py` → `build_autoconnect.py` und die Seite neu aufbauen
(bekannte Fallen stehen oben im Abschnitt „Stand 16.09.2026“).
Aktueller Stand: **122 Bauteile, 76 Netze, 348 live verdrahtete Pins** (die Netzliste hat 342 Zeilen;
die IR löst Sammel-Pins wie USB-C `VBUS`/`D+`/`D-` (je 2) und `GND` (6 Pads) einzeln auf ⇒ 348).

**Erledigt am 16.09.2026 (zweiter Neuaufbau, Review-Stand):** Geräte-UUIDs für `F1` (`C66503`,
Gehäuse `FUSE-SMD_L6.1-W2.7`) und `R_NTC_PAR` (`C17840`, `R0805`) aufgelöst, Pin-Tabellen per
Probe-Platzierung gemessen (beide 2-polig) → `raw/probe_review_2026-09-16.json`, `lcsc_map.json`
und `prefixes.json` ergänzt. Kette gelaufen: `build_ir` → `check_ir_netlist` (0 Abweichungen) →
`designators allocate` (0 funktionale Designatoren) → `plan_layout` (Fallback 0) →
`build_autoconnect` (14 Dateien). Seite geleert und neu aufgebaut: **122 Bauteile, 76 Netze**,
**348 Verbindungen** live, pin-für-pin gegen die Ziel-IR abgeglichen: **0 Abweichungen**;
20 NC-Marker auf den dokumentierten offenen Pins; Gate: `layout-lint`, `check`, `bridge-check`,
`drc` **grün**, `clusters` meldet 6 Beschriftungs-Überlappungen (rein optisch, so belassen).
Blattbild: `out/schaltplan_2026-09-16_2s_review.png`.

**Zwei Fallen, die Zeit gekostet haben:** (1) `measured_volumes_*.json` ist auf die jeweilige
Designator-Allokation geschlüsselt — nach einer Neuzuteilung per Device-UUID umschlüsseln, sonst
scheitert `plan_layout.py` (MCU-Block passt nicht). (2) `raw/place_all.sh`, `raw/frames.json` und
Gruppenlisten immer frisch erzeugen, nie aus einem älteren Lauf wiederverwenden (alte Designatoren).
Außerdem: `sch read` nennt das Pin-Feld `number`, `sch list --include-pins` dagegen `pinNumber`.

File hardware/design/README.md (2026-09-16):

# Design-Checks Schaltplan V1 (Stand 2S-Umbau, 16.09.2026)

Prüft den 2S-Schaltplan rechnerisch gegen die Datenblatt-Grenzwerte und
simuliert die kritischen Vorgänge. Nur Standardbibliothek, Python 3.9+.

Aufruf (aus `hardware/`):

    python3 -m design.report

Alternativ direkt: `python3 hardware/design/report.py`.
Exit-Code 0 = alle Prüfungen bestanden, 1 = mindestens eine fehlgeschlagen.

## Aufbau

* `circuit.py` — lädt Netzliste und Bauteilwerte. Bauteilwerte kommen
  ausschließlich über `circuit.part("<Designator>")` aus den Tabellen
  §3.1–§3.4 der `schaltplan_v1.md`. Systemgrößen (Pumpe, Pack, Modul, ADC,
  Netzteil) stehen im markierten `SYSTEM`-Block, jede mit ihrer wörtlichen
  Belegstelle. Annahmen stehen markiert in `ASSUMPTIONS`.
* `checks.py` — 42 Prüfungen. Jede liefert `name · Ist · Soll · Begründung`;
  hart verdrahtet sind nur Datenblattgrenzen mit Quellenangabe. Verwendet eine
  Prüfung einen Pin-/Bauteilnamen, den die Netzliste nicht kennt, bricht sie
  als **Werkzeugfehler** ab (`PruefFehler`, Exit 2) — das zählt *nicht* als
  fehlgeschlagene Prüfung und ist damit klar von einem Design-Fehler (Exit 1)
  getrennt.
* `sim.py` — Rechenproben (Gate-Treiber, Ladezeit CC/CV, Dosiervorgang,
  Pumpenanlauf, Buck-Rippel, Teilerströme, Standby in mAh/Tag).
* `report.py` — Ausgabe der Prüfungen und Simulationen.

## 2S-Prüfungen (neu)

Ladestrom IP2326 · Ladeschluss 2S · Ladeeingangsstrom ·
5-V-Buck-Ausgang · 3,3-V-Buck-Ausgang (FB direkt, kein Teiler) ·
5-V-Buck-Induktivität · 3,3-V-Buck-Induktivität · UVLO-Schwelle ·
UV-Teiler-Offset (Iq × R3a) · Gate-Pulldowns · ADC-Teiler Packspannung ·
Buck-EN-Pegel · Wächter-Abschaltung · VBAT-Spannungsfestigkeit ·
Standby-Budget · Systemquellen.

## Review-Fixes 16.09.2026 (in `checks.py` nachgezogen)

* **Pin-Name `5 D` statt `mb (Drain)`** an Q_PROT1/Q_PROT2 (gemessenes
  EasyEDA-Symbol des PSMN4R2-30MLDX). Ein unbekannter Pin-Name ist jetzt ein
  Werkzeugfehler (`PruefFehler`, Exit 2), kein Design-Fehler.
* **U_BUCK3 (AP63203) ist die Festspannungsversion:** `circuit.rail_3v3()`
  liefert den Datenblatt-Festwert 3,30 V; die Prüfung „3,3-V-Buck-Ausgang"
  bestätigt zusätzlich, dass FB (Pin 1) direkt auf `+3V3` liegt und weder
  `R_FB3_TOP/BOT` noch das Netz `FB_3V3` existieren.
* **Gate-Klemmzweig entfernt** (D3/D8/R_CLAMP1/2, KLAMP1/2): die Prüfungen
  „Wächter-Sinkstrom" und „Klemmzweig-Serie" sind durch **„Gate-Pulldowns"**
  (R2/R_GATE2_PD je 47 kΩ nach GND) und **„Wächter-Abschaltung"**
  (RESET_UV → U_BUCK5 EN; kein Klemmzweig-Rest mehr) ersetzt.
* **UV-Teiler 51 k/51 k:** neue Prüfung „UV-Teiler-Offset" rechnet den
  Iq-Offset als `Iq_max × R3a` (25,5 mV ≤ 50 mV) und den Teilerstrom
  (~82 µA ≙ ~2 mAh/Tag); „Teilerstrom" prüft beide Teiler zusammen
  (≤ 130 µA).
* **Sensorversorgung über Q_SENS:** neue Prüfung „Sensor-Lastschalter"
  (Source `+3V3`, Drain `SENSOR_PWR`, Gate `EXT_SENS_EN`, 47-kΩ-Pull-up nach
  `+3V3`, IO3 treibt nur das Gate, kein GPIO direkt an `SENSOR_PWR`/`VCC_EXT`).

## Akku-Schutz auf der Platine (neu 16.09.2026)

Serienkette · Schwellen · Überstrom. Die Schutz-Schwellen und die
Überstromschwelle werden wörtlich aus `../schaltplan_v1.md` gelesen (fehlt das
Muster, bricht die Prüfung ab); der Auslösestrom wird gegen den
Pumpenanlaufstrom gestellt.

## Quellen

`../schaltplan_v1_netzliste.csv`, `../schaltplan_v1.md`,
`../bom_entscheidung.md`, `../pcba_bom_jlc.csv`, `../../docs/11_review-2s-umbau.md`.
Die Quelldateien werden nur gelesen, nie geändert.

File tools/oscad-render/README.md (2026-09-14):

# oscad-render — headless OpenSCAD (WebAssembly)

Kleiner Renderer, der `.scad`-Dateien ohne GUI-Installation nach STL rendert.

**Warum nicht das native OpenSCAD?** Das Homebrew-Cask `openscad` wurde am 01.09.2026
deaktiviert („does not pass the macOS Gatekeeper check"), Docker ist auf diesem Rechner nicht
installiert. Derselbe OpenSCAD-Kern läuft als WebAssembly-Build aber einwandfrei.

## Nutzung

```bash
cd tools/oscad-render && npm install     # einmalig
node render.mjs <datei.scad> -o <ausgabe.stl>

Hinweis: Das Gehaeuse-CAD wurde am 14.09.2026 auf build123d umgestellt (`cad/`, siehe
`cad/README.md`). Dieser Renderer bleibt fuer einzelne SCAD-Dateien nutzbar.
```

Optionen:
- `-o <datei>` — Ausgabepfad (Standard: neben der Quelldatei)
- `-D name=wert` — Parameter überschreiben (mehrfach möglich, für Varianten/Testdrucke)

Alle `.scad`-Dateien im Verzeichnisbaum der Hauptdatei werden automatisch mitgeladen, damit
`include`/`use` funktionieren. Gerendert wird mit voller CGAL-Geometrie.

Exit-Code 0 = fehlerfrei (Facettenzahl wird ausgegeben). Exit-Code 1 = Fehler, unbekanntes
Modul/Variable, leeres Modell oder nicht-2-manifold-Geometrie.

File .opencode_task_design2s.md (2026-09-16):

# AUFGABE: Design-Prüfsuite (`hardware/design/`) auf die 2S-Schaltung umstellen

## Lage (16.09.2026)

Der Schaltplan wurde von **1S + Boost + LDO** auf **2S + zwei Abwärtswandler** umgebaut.
Verbindliche Quellen (NICHT ändern, nur lesen):

* `hardware/schaltplan_v1.md` — §1–§6 neuer Stand, §13 = Revisionsliste, §7–§12 Historie
* `hardware/schaltplan_v1_netzliste.csv` — 68 Netze, 115 Bauteile, 314 Verbindungen
* `hardware/pcba_bom_jlc.csv` — 109 bestückte Positionen
* `hardware/bom_entscheidung.md` — Bauteilentscheidungen (Pumpe, Akku, Sensor)
* `docs/11_review-2s-umbau.md` — das Review zum Umbau (Zahlen, Begründungen)

**Zustand der Suite:** sie läuft derzeit **gar nicht**.
`python3 hardware/design/report.py` bricht ab mit `Bauteil nicht in schaltplan_v1.md: R_PROG`;
`circuit.py` bricht in `load_system()` ab (`Kennwert 'Zellspannung' nicht gefunden`), weil die
Prosa-Regexe noch auf die 1S-Dokumente zeigen. Zusätzlich sind mehrere Prüfungen inhaltlich
überholt (MCP73831, ME6211, MT3608, MAX809).

## Ziel

`python3 hardware/design/report.py` läuft **sauber durch (Exit 0)** und prüft die **2S-Schaltung**
gegen die Datenblattgrenzen. Nur Standardbibliothek, Python 3.9+.

## Harte Regeln (nicht verhandelbar)

1. **Nur `hardware/design/*.py` ändern** (circuit.py, checks.py, sim.py, report.py, README.md dort).
   `schaltplan_v1.md`, `schaltplan_v1_netzliste.csv`, `pcba_bom_jlc.csv`, `bom_entscheidung.md`,
   `docs/*` **nicht anfassen**.
2. **Bauteilwerte werden GELESEN, nicht wiederholt.** Jeder Wert, der in einer Bauteiltabelle
   steht, ausschließlich über `circuit.part("<Designator>")` holen (die Tabellen in §3.1–§3.4
   enthalten alle Positionen mit Wert und LCSC).
3. **Nur Datenblattgrenzen dürfen im Code stehen**, jede mit Quellenkommentar
   (Datenblatt + Abschnitt). Systemgrößen (Pumpe, Pack, Modul, ADC) als ein klar markierter
   `SYSTEM`-Block mit Quelle — und mit einer Prüfung, die nachweist, dass diese Zahlen
   **wirklich in den Dokumenten vorkommen** (siehe `check_system_quellen`).
4. **Niemals still bestehen**: Passt ein Muster/Wert nicht, laut abbrechen (`CircuitError`) —
   eine Prüfung, die bei fehlendem Wert „grün" meldet, ist schlimmer als keine.
5. Keine Tautologien: eine Prüfung darf ihr Soll nicht aus derselben Zahl ableiten, die sie prüft.
6. Am Ende selbst laufen lassen und den Exit-Code prüfen; die Ausgabe muss jede Prüfung mit
   **Name · Ist · Soll · Begründung** zeigen.

## Kennwerte für die Prüfungen (Datenblatt-Anker, damit nichts geraten wird)

### Lader IP2326 (`U_CHG`, LCSC C2832094)
* Ladestrom **ICHG = 90000 / R_ISET** (Datenblatt V1.11 §„充电电流设置", S. 11). R_ISET ist im Plan **100 kΩ**.
  Grenzen: 0 … **1,5 A** (§7 Elektrische Eigenschaften, S. 4). ISET darf **nicht offen** sein (§4 Pin-Beschreibung).
* Ladeschluss: **VSET offen ⇒ 8,4 V** (Toleranz 8,3–8,5 V), §7/S. 4. ⚠️ Variante `IP2326_8V8` = 8,8 V → darf **nicht** bestellt sein (Textprüfung).
* Ladephasen (§9, S. 9): < 3,7 V → 50 mA · 3,7–6 V → 100 mA · > 6 V → ICC · ab ~8,4 V CV · Stopp bei 200–300 mA.
* Wirkungsgrad **94 %** bei 5 V → 8 V/1 A (§1, S. 1). Eingang 4,5–9,5 V (S. 3).
* CON_SEL offen ⇒ **2S** (§4/S. 8).

### 5-V-Buck SY8113B (`U_BUCK5`, C78989) — Datenblatt AN_SY8113B
* **V_out = 0,6 V × (1 + R_FB5_TOP/R_FB5_BOT)**, V_REF 0,6 V ±1,5 % (S. 1/S. 2).
* 3 A Ausgang (S. 1), Eingang 4,5–18 V, **f = 500 kHz**, Iq 100 µA, Shutdown 5–10 µA.
* EN: **High-Schwelle 1,5 V**, Low 0,4 V; Input-UVLO 4,5 V; „Do not float".
* Stromgrenzen: **Valley-Limit 3,0 … 4,25 A**, Top-FET-Peak 6 A (Elektrische Eigenschaften).
* R_DS(on) 80 mΩ (high) / 40 mΩ (low), θ_JA 100 °C/W, Sanftanlauf 800 µs.
* Induktivität: **L_BUCK5 = 4,7 µH, Isat 4,0 A** (Herstellerdatenblatt PRS6045), Rippel
  ΔI = (V_in − V_out) × D / (L × f) mit D = V_out/V_in.

### 3,3-V-Buck AP63203 (`U_BUCK3`, C780769) — Datenblatt DS41326
* **V_out = 0,8 V × (1 + R_FB3_TOP/R_FB3_BOT)**, V_REF 0,8 V ±1 %.
* 2 A, 3,8–32 V, **f = 1,1 MHz**, **Iq 22 µA**, θ_JA 89 °C/W, EN „Do not float".
* Zielbereich des Moduls (Espressif ESP32-C6-MINI-1): **V_DD33 3,0 … 3,6 V**.

### Unterspannungswächter TPS3839G33 (`U7`, C485802) — Datenblatt SBVS193D
* **V_IT = 3,003 … 3,126 V** (negativ), Hysterese 31 mV, **Iq 150 nA typ / 500 nA max**.
* V_DD 0,9 … 6,5 V; Ausgang **Push-Pull**, **V_OL ≤ 0,4 V bei I_OL = 2 mA** (2,8–6,5 V),
  **V_OH ≥ V_DD − 0,4 V**, Reset-Delay **200 ms**.
* Beschaltung im Plan: Teiler **R3a/R3b = 200 kΩ/200 kΩ** (Versorgung = VBAT/2),
  ⇒ Auslösung bei **V_trip = V_IT × (1 + R3a/R3b) + Iq × R3a**.
* Ziel: Abschaltung **2 × 3,0 V … 2 × 3,3 V** = **6,0 … 6,6 V** Packspannung.

### Klemmzweig (der wichtigste Regressionsschutz)
Der Klemmzweig **muss eine Serienkette** sein:
`GATE (bzw. GATE2) → R_CLAMP1/2 (10 kΩ) → D3/D8 → RESET_UV (U7 Pin 2)`.
Im Altstand lagen R_CLAMP und die Diode **parallel** und der Knoten hing an keinem Gate —
die Unterspannungsklemmung war wirkungslos (Befund 1 in `docs/11_review-2s-umbau.md`).
Diese Prüfung muss genau das erkennen können (siehe `check_klemmzweig_serie`).

### ADC (Espressif ESP32-C6, ADC1)
* 12 Bit, Bereich `ADC_ATTEN_DB_12` = **0 … 3300 mV**.
* Teiler: R_SENSE_TOP **200 kΩ** / R_SENSE_BOT **68 kΩ**; V_ADC = VBAT × R_bot/(R_top+R_bot)
  ⇒ bei 8,4 V **2,13 V**; Soll: ≤ 3300 mV **und** ≥ 1000 mV (Auflösungsreserve).

### Systemgrößen (Belegstellen — in `check_system_quellen` gegen die Dokumente prüfen)
| Größe | Wert | Belegstelle |
|---|---|---|
| Pack 2S | 7,4 V nominal, **6,0–8,4 V** Bereich, **2000 mAh** | `hardware/schaltplan_v1.md` §2.2/§6.3, `hardware/bom_entscheidung.md` §1 Zeile 4 |
| Pumpe Dosier | **5 V**, 0,4 A Leerlauf, **3 A Anlauf** | `hardware/bom_entscheidung.md` §1 Zeile 2, §4c |
| Pumpe O2 (optional) | 5 V, 0,2 A | `hardware/bom_entscheidung.md` §8 |
| Modul | TX-Peak **382 mA**, Deep-Sleep **7 µA** | `hardware/bom_entscheidung.md` §6.2, `hardware/schaltplan_v1.md` §6.2 |
| Ruhestrom-Bausteine | SY8113 **100 µA**, AP63203 **22 µA**, TPS3839 **0,15 µA** | Datenblätter (oben) |
| Netzteilannahme | **5 V / 2,5 A** | `hardware/schaltplan_v1.md` §6.1 |

## Aufgabe im Einzelnen

### 1. `circuit.py`
* `load_system()` **neu schreiben**: keine brüchigen Prosa-Regexe für Bauteilwerte mehr.
  Bauteilwerte über `part()`, Systemgrößen über den markierten `SYSTEM`-Block.
* Helfer behalten/ergänzen: `parse_ohm/parse_volt/parse_ampere` (Werte aus den Tabellen),
  `ratio(designator)` = R_top/R_bot, `net_of()`, `parts_on(net)`.
* Fehlt ein Bauteil oder ein Wert: `CircuitError` mit klarer Meldung.

### 2. `checks.py` — zu ersetzen (1S-Reste, alle lesen Werte, die es nicht mehr gibt)
`check_ladestrom` (MCP73831/R_PROG), `check_laderkondensatoren` (4,7 µF),
`check_max809_klemmstrom`, `check_ldo_reserve`, `check_ldo_headroom`.
Außerdem: die statische Kanal-Liste enthält noch **J14** — J14 ist seit 15.09.2026 entfernt
(IO22 ist jetzt PUMP2_EN/J16); Eintrag entfernen.

### 3. `checks.py` — neu (Name → Formel → Soll → Quelle)
| Prüfung | Formel / Inhalt | Soll | Quelle |
|---|---|---|---|
| `check_ladestrom_ip2326` | ICHG = 90000/R_ISET | ≤ 1,5 A **und** ≤ 1 C des Packs | IP2326 S. 4/S. 11 |
| `check_ladeschluss_2s` | 2 × 4,2 V gegen VSET-offen-Wert + Textprüfung „kein IP2326_8V8 im BOM" | 8,4 V ±0,1 V, kein 8V8 | IP2326 S. 4/S. 5 |
| `check_ladeeingang_strom` | I_in = V_out·I_CHG/(η·V_USB) + Systemlast | ≤ 2,5 A (Netzteilannahme) | IP2326 S. 1 (94 %) |
| `check_buck5_ausgang` | 0,6 × (1 + R_FB5_TOP/R_FB5_BOT) | 5,0 V ±5 % (Pumpennennspannung) | SY8113B S. 1/S. 2 |
| `check_buck3_ausgang` | 0,8 × (1 + R_FB3_TOP/R_FB3_BOT) | 3,0 … 3,6 V | AP63203 + Espressif |
| `check_buck5_induktivitaet` | I_peak = I_Last + ΔI/2, ΔI = (V_in−V_out)·D/(L·f), D = V_out/V_in; V_in = 8,4 V **und** 6,16 V | I_peak < 4,0 A (Isat), I_Last ≤ 3 A | PRS6045 + SY8113B S. 1 |
| `check_buck3_induktivitaet` | dito mit 1,1 MHz | I_peak < 4,0 A | PRS6045 + AP63203 |
| `check_uvlo_schwelle` | V_trip = V_IT·(1+R3a/R3b) + Iq·R3a | 6,0 … 6,6 V | TPS3839 S. 7 |
| `check_waechter_sinkstrom` | 2 × (V_rail − V_F)/R_CLAMPx + EN-Leckstrom | ≤ 2 mA (V_OL = 0,4 V) | TPS3839 „Pin Functions"/EC |
| `check_adc_teiler_max` | V_ADC = VBAT_max · R_SENSE_BOT/(R_SENSE_TOP+R_SENSE_BOT) | ≤ 3,3 V **und** ≥ 1,0 V | Espressif ADC 12 dB |
| `check_buck_en_pegel` | V_OH_Wächter = V_DD − 0,4 V gegen EN-Schwelle 1,5 V | V_OH > 1,5 V | TPS3839 + SY8113B |
| `check_klemmzweig_serie` | Netzlistenprüfung: GATE→R_CLAMP1→D3→RESET_UV und GATE2→R_CLAMP2→D8→RESET_UV als **Serie** | genau diese Topologie | Review §5 Befund 1 |
| `check_kein_low_vin_am_vbat` | Kein Bauteil mit V_IN,max < 8,4 V darf auf dem Netz VBAT liegen (Liste der erlaubten VBAT-Teilnehmer + Datenblatt-V_IN,max je Teil) | nur Bauteile mit ausreichender Spannungsfestigkeit | ME6211-Lektion, Review §5 Befund 4 |
| `check_standby_budget` | Iq_Buck5 + Iq_Buck3 + Iq_Wächter + Teilerströme + Modul-Sleep | ≤ 250 µA; Ausgabe in mAh/Tag | Datenblätter |
| `check_system_quellen` | die Zahlenwerte des `SYSTEM`-Blocks müssen als Text in den Dokumenten vorkommen | jeder Wert belegt | Regel 3 oben |

### 4. `checks.py` — bestehende Prüfungen behalten und auf die neuen Rails ziehen
`check_gate_spannung`, `check_mosfet_verlust`, `check_freilaufdiode`, `check_teilerstrom`,
`check_uv_staffelung`, `check_adc_filter`, `check_light_*`, `check_led_*`, `check_btn_*`,
`check_pin_disziplin`, `check_stecker_pinordnung`, `check_erweiterung_*`, `check_load_switch_failsafe`,
`check_i2c_pullups`, `check_en_rc`, `check_netzstruktur`.
Anpassungen: Logikrail heißt weiterhin `+3V3` (jetzt 3,31 V statt 3,30 V), Pumpenrail `+5V`
(jetzt 5,10 V aus dem Buck statt Boost), `check_uv_staffelung` jetzt gegen **6,16 V** statt 3,08 V.
Rail-Spannungen **aus den Feedback-Teilern berechnen**, nicht abtippen.

### 5. `sim.py`
Rechenproben aktualisieren: Ladezeit (CC/CV grob) für 2000 mAh bei 0,90 A · Laufzeit je Dosiervorgang
aus der 5-V-Schiene · Teilerströme · Buck-Rippelströme · Standby in mAh/Tag. Getroffene Annahmen
im Code als Annahme kennzeichnen (z. B. Innenwiderstand des Packs) und in der Ausgabe nennen.

### 6. `report.py`
Mechanik behalten (Tabelle, Exit 1 bei jedem Fehlschlag). Nur wenn eine Prüfung entfällt, den Aufruf
entfernen. Die Ausgabe muss die neuen Prüfungen vollständig zeigen.

## Abnahme (bitte selbst nachweisen und im Bericht nennen)
1. `python3 hardware/design/report.py` → **Exit 0**, Anzahl Prüfungen und Zeilen ausgeben.
2. `python3 hardware/design/report.py; echo "exit=$?"` — Exit-Code wirklich prüfen.
3. Eine **Gegenprobe** zeigen (kurz im Bericht): einen Wert im Dokument versuchsweise ändern
   (z. B. R_FB5_TOP von 75 kΩ auf 100 kΩ im TEXT kopieren und wieder zurücksetzen) und belegen,
   dass die zugehörige Prüfung **rot** wird — danach zurücksetzen (Datei unverändert lassen!).
4. `python3 -m py_compile hardware/design/*.py` ohne Fehler.

## Bericht (kurz)
* Geänderte Dateien + je eine Zeile, was passiert ist
* Anzahl Prüfungen (vorher/nachher), Exit-Codes
* Welche Prüfungen entfallen sind und wodurch sie ersetzt wurden
* Alles, was NICHT umgesetzt werden konnte, mit Grund

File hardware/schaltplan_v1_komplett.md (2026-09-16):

# SmartGrowTopf_V1 - vollstaendige Schaltungsbeschreibung (Maschinenfassung)

Stand 16.09.2026, **inklusive der Nachbesserungen aus dem externen Review** (siehe
`docs/12_review-nachbesserungen.md`). Erzeugt **maschinell aus der Netzliste**
(`hardware/schaltplan_v1_netzliste.csv`), der Stueckliste (`hardware/pcba_bom_jlc.csv`) und dem
Protokoll der Design-Pruefsuite (`hardware/design/report.py`). Keine Zahl ist abgetippt.

> Hinweis: Die EasyEDA-Bauseite wird erst im naechsten Durchgang auf diesen Stand gezogen; die
> Blockkoordinaten des Blatts (Abschnitt 4) sind daher noch der Stand vor dieser Runde.

## 1. Kennzahlen und Versorgungskette

| Kennzahl | Wert |
|---|---|
| Bauteile mit Bezeichner | **122** |
| Netze | **76** |
| Verbindungen (Pin -> Netz) | **342** |
| Module | **12** |
| Steckverbinder (J*) | **16** |
| Testpunkte (TP*) | **6** |

**Versorgungskette (2S):**

```
USB-C 5 V --> IP2326 (Boost-Lader, 8,4 V / 0,90 A) --> VBAT = 2S-Pack (6,0 - 8,4 V)
                                                            |
2S-Pack an J1 (3-polig: B- / Mittelabgriff / B+) --> F1 5 A traege
     --> HY2120-Schutz (Q3/Q4 in der Minusleitung; BAT_MINUS ist NICHT Board-GND)
                                                            |
                       +------------------------------------+------------------------------------+
                       |                                                                         |
          SY8113B-Buck 3 A --> +5 V                                  AP63203-Buck 2 A --> +3,3 V
          (Dosierpumpe J4, Sauerstoffpumpe J16,                       (ESP32-C6, Sensorik ueber
           Sensor-5-V-Ausgang J17)                                    Q_SENS, LEDs, I2C)

Akku-Temperatur: J18 (XH-2P) --> NTC 100 kOhm B3950 || 82 kOhm --> IP2326 Pin 4 (NTC)
     Schwellen 0 / 45 / 55 Grad C; Stecker ab ==> Lader laedt nicht (fail-safe)
```

In Worten: 5 V kommen ueber USB-C; der **IP2326** laedt daraus den 2S-Pack auf 8,4 V. Der Pack geht
ueber den **3-poligen Stecker J1** und die **Sicherung F1** auf die Platine. Der **HY2120** trennt
mit zwei MOSFETs Pack-Minus und Board-Masse und ueberwacht jede Zelle; der **IP2326** nutzt den
Mittelabgriff zusaetzlich zum Balancieren. Aus VBAT erzeugen zwei Abwaertswandler **+5 V** und
**+3,3 V**. Es gibt **keinen LDO** und keinen zusaetzlichen Aufwaertswandler fuer die Lastversorgung
(der IP2326 ist selbst ein Boost-Lader).

## 2. Was ist verbaut

| Ref | Modul | Typ / Wert | Gehaeuse | LCSC | Funktion |
|---|---|---|---|---|---|
| **C1a** | - | 100nF | 0805 | `C49678` | 100nF |
| **C1b** | - | 100nF | 0805 | `C49678` | 100nF |
| **C_B3_BST** | - | 100nF | 0805 | `C49678` | 100nF |
| **C_B3_IN** | - | 22uF 25V | 0805 | `C45783` | 22uF 25V |
| **C_B3_IN_HF** | - | 100nF | 0805 | `C49678` | 100nF |
| **C_B3_OUT** | - | 22uF 25V | 0805 | `C45783` | 22uF 25V |
| **C_B3_OUT_HF** | - | 100nF | 0805 | `C49678` | 100nF |
| **C_B5_BST** | - | 100nF | 0805 | `C49678` | 100nF |
| **C_B5_IN** | - | 22uF 25V | 0805 | `C45783` | 22uF 25V |
| **C_B5_IN_HF** | - | 100nF | 0805 | `C49678` | 100nF |
| **C_B5_OUT** | - | 22uF 25V | 0805 | `C45783` | 22uF 25V |
| **C_B5_OUT_HF** | - | 100nF | 0805 | `C49678` | 100nF |
| **C_BST_CHG** | - | 100nF | 0805 | `C49678` | 100nF |
| **C_BTN** | - | 100nF | 0805 | `C49678` | 100nF |
| **C_CHG_IN** | - | 10uF 25V | 0805 | `C15850` | 10uF 25V |
| **C_CHG_OUT** | - | 10uF 25V | 0805 | `C15850` | 10uF 25V |
| **C_CHG_VIN** | - | 10uF 25V | 0805 | `C15850` | 10uF 25V |
| **C_LIGHT** | - | 100nF | 0805 | `C49678` | 100nF |
| **C_PROT_VC** | - | 100nF | 0805 | `C49678` | 100nF |
| **C_PROT_VDD** | - | 100nF | 0805 | `C49678` | 100nF |
| **C_PUMP2_EMI** | - | 100nF | 0805 | `C49678` | 100nF |
| **C_SPARE** | - | 100nF | 0805 | `C49678` | 100nF |
| **C_VSYS_A** | - | 22uF 25V | 0805 | `C45783` | 22uF 25V |
| **C_VSYS_B** | - | 22uF 25V | 0805 | `C45783` | 22uF 25V |
| **D_FLY2** | - | 1N5819WS | SOD-323 | `C191023` | 1N5819WS |
| **D_LEDCHG** | - | LED-RED | 0805 | `C84256` | LED-RED |
| **L_BUCK3** | - | 4.7uH Isat 4,0A DCR 31mR | SMD 6x6mm | `C105660` | 4.7uH Isat 4,0A DCR 31mR |
| **L_BUCK5** | - | 4.7uH Isat 4,0A DCR 31mR | SMD 6x6mm | `C105660` | 4.7uH Isat 4,0A DCR 31mR |
| **L_CHG** | - | 2.2uH Isat 5,0A DCR 58mR | SMD 4.6x4.1mm | `C142096` | 2.2uH Isat 5,0A DCR 58mR |
| **Q_PROT1** | - | PSMN4R2-30MLDX | LFPAK33-8 | `C179452` | PSMN4R2-30MLDX |
| **Q_PROT2** | - | PSMN4R2-30MLDX | LFPAK33-8 | `C179452` | PSMN4R2-30MLDX |
| **Q_PUMP2** | - | AO3400A | SOT-23 | `C20917` | AO3400A |
| **R3a** | - | 51k | 0805 | `C17737` | 51k |
| **R3b** | - | 51k | 0805 | `C17737` | 51k |
| **R5a** | - | 5.1k | 0805 | `C27834` | 5.1k |
| **R5b** | - | 5.1k | 0805 | `C27834` | 5.1k |
| **R_BOOT** | - | 10k | 0805 | `C17414` | 10k |
| **R_BTN** | - | 10k | 0805 | `C17414` | 10k |
| **R_CB** | - | 100R 0,25W | 1206 | `C17901` | 100R 0,25W |
| **R_EN** | - | 10k | 0805 | `C17414` | 10k |
| **R_EN_CHG** | - | 100k 1% | 0805 | `C96346` | 100k 1% |
| **R_FB5_BOT** | - | 10k | 0805 | `C17414` | 10k |
| **R_FB5_TOP** | - | 75k | 0805 | `C17819` | 75k |
| **R_GATE** | - | 47k | 0805 | `C17713` | 47k |
| **R_GATE2** | - | 1k | 0805 | `C17513` | 1k |
| **R_GATE2_PD** | - | 47k | 0805 | `C17713` | 47k |
| **R_GPIO8** | - | 10k | 0805 | `C17414` | 10k |
| **R_ISET** | - | 100k 1% | 0805 | `C96346` | 100k 1% |
| **R_LEDCHG** | - | 1k | 0805 | `C17513` | 1k |
| **R_LIGHT** | - | 10k | 0805 | `C17414` | 10k |
| **R_LIGHT_S** | - | 1k | 0805 | `C17513` | 1k |
| **R_PROT_CS** | - | 2k | 0805 | `C17604` | 2k |
| **R_PROT_VC** | - | 330R | 0805 | `C17630` | 330R |
| **R_PROT_VDD** | - | 330R | 0805 | `C17630` | 330R |
| **R_SCL_PU** | - | 4.7k | 0805 | `C17673` | 4.7k |
| **R_SCL_S** | - | 1k | 0805 | `C17513` | 1k |
| **R_SDA_PU** | - | 4.7k | 0805 | `C17673` | 4.7k |
| **R_SDA_S** | - | 1k | 0805 | `C17513` | 1k |
| **R_SENSE_BOT** | - | 68k | 0805 | `C17801` | 68k |
| **R_SENSE_TOP** | - | 200k | 0805 | `C17539` | 200k |
| **R_SPARE_AIN** | - | 1k | 0805 | `C17513` | 1k |
| **R_SPARE_IO15** | - | 1k | 0805 | `C17513` | 1k |
| **R_SPARE_IO16** | - | 1k | 0805 | `C17513` | 1k |
| **R_SPARE_IO17** | - | 1k | 0805 | `C17513` | 1k |
| **R_SPARE_IO21** | - | 1k | 0805 | `C17513` | 1k |
| **R_SPARE_IO23** | - | 1k | 0805 | `C17513` | 1k |
| **R_TANK** | - | 1k | 0805 | `C17513` | 1k |
| **R_UART** | - | 499R | 0805 | - | 499R |
| **R_UVSET** | - | 68k | 0805 | `C17801` | 68k |
| **R_VIN_CHG** | - | 0.5R | 0805 | `C28319` | 0.5R |
| **U_BUCK3** | - | AP63203WU-7 | TSOT-23-6 | `C780769` | AP63203WU-7 |
| **U_BUCK5** | - | SY8113B ADC | TSOT-23-6 | `C78989` | SY8113B ADC |
| **U_CHG** | - | IP2326 | VQFN-24-EP(4x4) | `C2832094` | IP2326 |
| **U_PROT** | - | HY2120-CB | SOT-23-6 | `C116509` | HY2120-CB |
| **C3** | Akku und Pack | 100uF 16V | SMD D6.3x5.4 | `C970684` | Elko 100 uF Pumpenpuffer auf +5V |
| **F1** | Akku und Pack | 5A traege 2410 | 2410 | `C66503` | Sicherung in der Pack-Plus-Leitung, 5 A traege (2410) |
| **J1** | Akku und Pack | JST-XH-3P | THT P2.5 aufrecht (Top-Entry) | `C5258884` | Akku JST-XH 3P (B-/MID/B+), aufrecht |
| **TP3** | Akku und Pack | - | - | - | Testpad GND |
| **TP4** | Akku und Pack | - | - | - | Testpad VBAT |
| **TP1** | UART-Debug-Pads (DNP) | - | - | - | Testpad TXD0 |
| **J10** | Erweiterung | Stiftleiste-1x3-2.54mm | THT P2.54 gerade | `C2937625` | Reserve IO15 Stiftleiste 1x3 |
| **J11** | Erweiterung | Stiftleiste-1x3-2.54mm | THT P2.54 gerade | `C2937625` | Reserve IO16 (TXD0) Stiftleiste 1x3 |
| **J12** | Erweiterung | Stiftleiste-1x3-2.54mm | THT P2.54 gerade | `C2937625` | Reserve IO17 (RXD0) Stiftleiste 1x3 |
| **J13** | Erweiterung | Stiftleiste-1x3-2.54mm | THT P2.54 gerade | `C2937625` | Reserve IO21 Stiftleiste 1x3 |
| **J15** | Erweiterung | Stiftleiste-1x3-2.54mm | THT P2.54 gerade | `C2937625` | Reserve IO23 Stiftleiste 1x3 |
| **J8** | Erweiterung | Stiftleiste-1x4-2.54mm | THT P2.54 gerade | `C2691448` | I2C-Stiftleiste 1x4 (GND-VCC-SDA-SCL) |
| **J9** | Erweiterung | Stiftleiste-1x3-2.54mm | THT P2.54 gerade | `C2937625` | Reserve-Analog Stiftleiste 1x3 (IO5) |
| **Q2** | Erweiterung | AO3401A | SOT-23 | `C15127` | P-Kanal-Load-Switch VCC_EXT |
| **J18** | Laden (IP2326, 2S) | JST-XH-2P | THT P2.5 aufrecht (Top-Entry) | `C158012` | Stecker fuer den Akku-Temperatursensor (XH-2P, 1 = NTC-Signal, 2 = GND) |
| **R_NTC_PAR** | Laden (IP2326, 2S) | 82k 1% | 0805 | `C17840` | 82 kOhm parallel zum NTC - legt die Schwellen auf 0 / 45 / 55 Grad C |
| **TP5** | 3V3-Buck (AP63203) | - | - | - | Testpad +3V3 |
| **J7** | Lichtsensor | Stiftleiste-1x3-2.54mm | THT P2.54 gerade | `C2937625` | Lichtsensor-Stiftleiste 1x3 2,54 mm |
| **C10** | ESP32-C6 | 100nF | 0805 | `C49678` | ADC-Filter VBAT 100 nF |
| **C13** | ESP32-C6 | 100nF | 0805 | `C49678` | Decoupling Modul 100 nF |
| **C2** | ESP32-C6 | 22uF 25V | 0805 | `C45783` | Bulk 22 uF am Modul-3V3 |
| **C4** | ESP32-C6 | 1uF | 0603 | `C15849` | EN-RC 1 uF |
| **C9** | ESP32-C6 | 100nF | 0805 | `C49678` | ADC-Filter Sensor 100 nF |
| **D2** | ESP32-C6 | LED-GREEN | 0805 | `C2297` | Status-LED gruen 525 nm |
| **D5** | ESP32-C6 | LED-RED | 0805 | `C84256` | Tank-leer-LED rot |
| **R4** | ESP32-C6 | 220R | 0805 | `C17557` | Status-LED 220 R |
| **SW1** | ESP32-C6 | SW-SMD | SMD-4P 5.1x5.1 | `C318884` | Reset-Taster |
| **SW2** | ESP32-C6 | SW-SMD | SMD-4P 5.1x5.1 | `C318884` | Boot-Taster |
| **TP2** | ESP32-C6 | - | - | - | Testpad RXD0 |
| **U1** | ESP32-C6 | ESP32-C6-MINI-1 | SMD-53P | `C5736265` | ESP32-C6-MINI-1 WLAN-Modul |
| **C11** | Pumpentreiber | 100nF | 0805 | `C49678` | EMI an den Pumpenklemmen 100 nF |
| **D1** | Pumpentreiber | 1N5819WS | SOD-323 | `C191023` | Freilaufdiode Dosierpumpe |
| **J16** | Pumpentreiber | JST-XH-2P | THT P2.5 aufrecht (Top-Entry) | `C158012` | Sauerstoffpumpe JST-XH 2P, aufrecht |
| **J4** | Pumpentreiber | JST-XH-2P | THT P2.5 aufrecht (Top-Entry) | `C158012` | Dosierpumpe JST-XH 2P, aufrecht |
| **Q1** | Pumpentreiber | AO3400A | SOT-23 | `C20917` | N-MOSFET Pumpentreiber Dosierpumpe |
| **R1** | Pumpentreiber | 1k | 0805 | `C17513` | Gate-Serie 1 k |
| **R2** | Pumpentreiber | 47k | 0805 | `C17713` | Gate-Pulldown 47 k |
| **J17** | Sensor-Eingang | JST-XH-2P | THT P2.5 aufrecht (Top-Entry) | `C158012` | 5-V-Ausgang fuer Sensorik JST-XH 2P |
| **J2** | Sensor-Eingang | JST-XH-3P | THT P2.5 aufrecht (Top-Entry) | `C5258884` | Feuchtesensor JST-XH 3P, aufrecht |
| **Q_SENS** | Sensor-Eingang | AO3401A | SOT-23 | `C15127` | P-Kanal-Lastschalter der Sensorversorgung (Source +3V3, Drain SENSOR_PWR) |
| **R6** | Sensor-Eingang | 1k | 0805 | `C17513` | Sensor-AOUT Serie 1 k |
| **R_SENS_GATE** | Sensor-Eingang | 47k | 0805 | `C17713` | 47 kOhm Gate-Pull-up: Sensor-Lastschalter ohne Freigabe sicher aus |
| **TP6** | Sensor-Eingang | - | - | - | Testpad SENSOR_AOUT |
| **J6** | Taster und LEDs | - | 2x Loch 1.0mm Raster 2.54mm | - | 2 Loetpads externer Taster |
| **J5** | USB-C Eingang | USB-C-16P | SMD | `C165948` | USB-C 16P Buchse (Laden + Programmieren) |
| **U6** | USB-C Eingang | USBLC6-2SC6 | SOT-23-6L | `C7519` | USB-ESD-Schutz USBLC6-2SC6 |
| **C12** | Unterspannungswaechter | 100nF | 0805 | `C49678` | Decoupling Waechter 100 nF |
| **U7** | Unterspannungswaechter | TPS3839G33DBZR | SOT-23-3 | `C485802` | Unterspannungswaechter TPS3839G33 (3,08 V) |

## 3. Wie ist verkabelt (jedes Netz mit jedem Pin)

### `+3V3`

Pins: 19

- `C13:1` - ESP32-C6  *(Hinweis: 100 nF)*
- `C1a:1` - -  *(Hinweis: 100 nF)*
- `C1b:1` - -  *(Hinweis: 100 nF)*
- `C2:1` - ESP32-C6  *(Hinweis: 22 uF Bulk am Modul)*
- `C_B3_OUT:1` - -  *(Hinweis: 22 uF Keramik am Ausgang nach GND)*
- `C_B3_OUT_HF:1` - -  *(Hinweis: 100 nF HF am Ausgang nach GND)*
- `L_BUCK3:2` - -  *(Hinweis: Ausgangsknoten der Logikversorgung)*
- `Q2:2 Source` - Erweiterung  *(Hinweis: P-Kanal-Load-Switch Source)*
- `Q_SENS:2 Source` - Sensor-Eingang  *(Hinweis: P-Kanal-Lastschalter Sensorversorgung (Source an 3,3 V))*
- `R_BOOT:1` - -  *(Hinweis: 10 kOhm Pull-up GPIO9)*
- `R_BTN:1` - -  *(Hinweis: 10 kOhm Pull-up fuer den externen Taster)*
- `R_EN:1` - -  *(Hinweis: 10 kOhm Pull-up EN)*
- `R_GATE:1` - -  *(Hinweis: 47 kOhm Gate-Pull-up des Load-Switch (aus = Fail-safe))*
- `R_GPIO8:1` - -  *(Hinweis: 10 kOhm Pull-up GPIO8 (eigene Auslegung))*
- `R_SENS_GATE:2` - Sensor-Eingang  *(Hinweis: 47 k Gate-Pull-up: ohne Freigabe ist der Lastschalter sicher aus)*
- `TP5:1` - 3V3-Buck (AP63203)  *(Hinweis: Testpad +3V3)*
- `U1:3 3V3` - ESP32-C6  *(Hinweis: Modulversorgung)*
- `U1:VDD33 (alle)` - ESP32-C6  *(Hinweis: mehrere Pins laut Espressif Pin-Layout)*
- `U_BUCK3:1 FB` - -  *(Hinweis: Festspannungsversion AP63203: FB direkt auf den Ausgang, VFB = 3,30 V - kein Teiler (Datenblatt Fig. 21))*

### `+5V`

Pins: 12

- `C11:2` - Pumpentreiber  *(Hinweis: EMI-Kondensator ueber den Motorklemmen (Minus geschaltet ueber Q1))*
- `C3:+` - Akku und Pack  *(Hinweis: 100 uF Elko (von VBAT hierher verschoben) - POLARITAET beachten)*
- `C_B5_OUT:1` - -  *(Hinweis: 22 uF Keramik am Ausgang nach GND)*
- `C_B5_OUT_HF:1` - -  *(Hinweis: 100 nF HF am Ausgang nach GND)*
- `C_PUMP2_EMI:2` - -  *(Hinweis: EMI-Kondensator ueber den Klemmen der Sauerstoffpumpe (Minus geschaltet ueber Q3))*
- `D1:Kathode` - Pumpentreiber  *(Hinweis: Freilaufdiode Dosierpumpe)*
- `D_FLY2:Kathode` - -  *(Hinweis: Freilaufdiode Sauerstoffpumpe)*
- `J16:1` - Pumpentreiber  *(Hinweis: Sauerstoffpumpe +)*
- `J17:1` - Sensor-Eingang  *(Hinweis: 5-V-Ausgang fuer Sensorik (neu) - Pin 1)*
- `J4:1` - Pumpentreiber  *(Hinweis: Dosierpumpe +)*
- `L_BUCK5:2` - -  *(Hinweis: Ausgangsknoten der 5-V-Schiene)*
- `R_FB5_TOP:1` - -  *(Hinweis: Feedback oben 75 k -> Vout = 0,6 V x (1 + 75/10) = 5,10 V)*

### `VBAT`

Pins: 15

- `C_B3_IN:1` - -  *(Hinweis: 22 uF Keramik am Buck-Eingang nach GND)*
- `C_B3_IN_HF:1` - -  *(Hinweis: 100 nF HF am Buck-Eingang nach GND)*
- `C_B5_IN:1` - -  *(Hinweis: 22 uF Keramik am Buck-Eingang nach GND)*
- `C_B5_IN_HF:1` - -  *(Hinweis: 100 nF HF am Buck-Eingang nach GND)*
- `C_CHG_OUT:1` - -  *(Hinweis: 10 uF Keramik am Ausgang (Datenblatt C6/C7))*
- `F1:2` - Akku und Pack  *(Hinweis: 5-A-Sicherung (traege, 2410): schuetzt Akkukabel und Stecker. Die 17-A-Schwelle des HY2120 ist dafuer zu hoch (Review 16.09.2026))*
- `R3a:1` - -  *(Hinweis: UVLO-Teiler oben 51 k)*
- `R_PROT_VDD:1` - -  *(Hinweis: 330 R zum VDD-Pin des Schutz-IC (Datenblatt-Typwert))*
- `R_SENSE_TOP:1` - -  *(Hinweis: ADC-Teiler oben 200 k)*
- `TP4:1` - Akku und Pack  *(Hinweis: Testpad VBAT)*
- `U_BUCK3:2 EN` - -  *(Hinweis: EN fest an VIN - 3,3-V-Schiene ist immer an (MCU muss im Waechterfall leben))*
- `U_BUCK3:3 VIN` - -  *(Hinweis: Eingang 3,3-V-Buck)*
- `U_BUCK5:5 IN` - -  *(Hinweis: Eingang 5-V-Buck)*
- `U_CHG:21 VOUT` - -  *(Hinweis: Boost-Ausgang -> Akku-Plus (Datenblatt: "VOUT 接电池正极"))*
- `U_CHG:22 VOUT` - -

### `PACK_PLUS`

Pins: 2

- `F1:1` - Akku und Pack
- `J1:3` - Akku und Pack  *(Hinweis: Akku-Pack Plus (Zelle 2 +) - Packseite, VOR der Sicherung)*

### `VBUS`

Pins: 7

- `C_CHG_IN:1` - -  *(Hinweis: 10 uF Keramik am Eingang (Datenblatt C1) - 25 V, weil Eingang bis 9,5 V zugelassen)*
- `J5:VBUS (A4/A9/B4/B9)` - USB-C Eingang  *(Hinweis: USB-Eingang 5 V - alle vier VBUS-Pins verbinden)*
- `L_CHG:1` - -  *(Hinweis: Induktivitaet 2.2 uH - andere Seite am Schaltknoten LX_CHG)*
- `R_EN_CHG:1` - -  *(Hinweis: 100 kOhm Pull-up des Lader-EN - Laden ist an, sobald USB steckt, ohne MCU)*
- `R_LEDCHG:1` - -  *(Hinweis: 1 kOhm Vorwiderstand der Lade-LED (ca. 2,7 mA aus 5 V))*
- `R_VIN_CHG:1` - -  *(Hinweis: 0.5 Ohm Filterwiderstand zum VIN-Pin (Datenblatt R1) - KEIN Ladestrom-Shunt)*
- `U6:5 VBUS` - USB-C Eingang  *(Hinweis: ESD-Referenz)*

### `VBUS_CHG`

Pins: 3

- `C_CHG_VIN:1` - -  *(Hinweis: 10 uF direkt am VIN-Pin (Datenblatt C3))*
- `R_VIN_CHG:2` - -  *(Hinweis: Filterspannung fuer den VIN-Pin)*
- `U_CHG:13 VIN` - -  *(Hinweis: mit C_CHG_VIN gepuffert)*

### `VSYS_CHG`

Pins: 4

- `C_VSYS_A:1` - -  *(Hinweis: 22 uF direkt am VSYS-Pin (Datenblatt C4))*
- `C_VSYS_B:1` - -  *(Hinweis: 22 uF direkt am VSYS-Pin (Datenblatt C5))*
- `U_CHG:19 VSYS` - -  *(Hinweis: Zwischenknoten des Boost-Ausgangs)*
- `U_CHG:20 VSYS` - -

### `BAT_MINUS`

Pins: 8

- `C_PROT_VC:2` - -  *(Hinweis: VC-Filterkondensator nach Pack-Minus)*
- `C_PROT_VDD:2` - -  *(Hinweis: VDD-Filterkondensator nach Pack-Minus)*
- `J1:1` - Akku und Pack  *(Hinweis: Akku-Pack-Minus (Zelle 1 -) - liegt NICHT auf Board-GND)*
- `Q_PROT1:1 S` - -  *(Hinweis: Source des Entlade-MOSFET (Pinning: 1/2/3 = Source))*
- `Q_PROT1:2 S` - -
- `Q_PROT1:3 S` - -
- `U_CHG:24 BAT_GND` - -  *(Hinweis: Bezug des internen Balancing (Datenblatt-Applikation: BAT- an Pin 24))*
- `U_PROT:6 VSS` - -  *(Hinweis: Masse des Schutz-IC = Pack-Minus (Datenblatt 5.2))*

### `VCC_EXT`

Pins: 10

- `J10:2` - Erweiterung  *(Hinweis: Reserve IO15 VCC (geschaltet))*
- `J11:2` - Erweiterung  *(Hinweis: Reserve IO16 VCC (geschaltet))*
- `J12:2` - Erweiterung  *(Hinweis: Reserve IO17 VCC (geschaltet))*
- `J13:2` - Erweiterung  *(Hinweis: Reserve IO21 VCC (geschaltet))*
- `J15:2` - Erweiterung  *(Hinweis: Reserve IO23 VCC (geschaltet))*
- `J8:2` - Erweiterung  *(Hinweis: geschaltete Erweiterungsversorgung)*
- `J9:2` - Erweiterung  *(Hinweis: Reserve-Analog VCC (geschaltet))*
- `Q2:3 Drain` - Erweiterung  *(Hinweis: P-Kanal-Load-Switch)*
- `R_SCL_PU:2` - -
- `R_SDA_PU:2` - -

### `GND`

Pins: 89

- `C10:2` - ESP32-C6
- `C12:2` - Unterspannungswaechter
- `C13:2` - ESP32-C6
- `C1a:2` - -
- `C1b:2` - -
- `C2:2` - ESP32-C6
- `C3:-` - Akku und Pack  *(Hinweis: Elko-Minus (liegt auf der 5-V-Schiene))*
- `C4:2` - ESP32-C6
- `C9:2` - ESP32-C6
- `C_B3_IN:2` - -
- `C_B3_IN_HF:2` - -
- `C_B3_OUT:2` - -
- `C_B3_OUT_HF:2` - -
- `C_B5_IN:2` - -
- `C_B5_IN_HF:2` - -
- `C_B5_OUT:2` - -
- `C_B5_OUT_HF:2` - -
- `C_BTN:2` - -
- `C_CHG_IN:2` - -
- `C_CHG_OUT:2` - -
- `C_CHG_VIN:2` - -
- `C_LIGHT:2` - -  *(Hinweis: ADC-Filter Lichtsensor)*
- `C_SPARE:2` - -  *(Hinweis: ADC-Filter Reserve-Analog)*
- `C_VSYS_A:2` - -
- `C_VSYS_B:2` - -
- `D2:Kathode` - ESP32-C6
- `D5:Kathode` - ESP32-C6
- `J10:1` - Erweiterung  *(Hinweis: Reserve IO15 GND)*
- `J11:1` - Erweiterung  *(Hinweis: Reserve IO16 GND)*
- `J12:1` - Erweiterung  *(Hinweis: Reserve IO17 GND)*
- `J13:1` - Erweiterung  *(Hinweis: Reserve IO21 GND)*
- `J15:1` - Erweiterung  *(Hinweis: Reserve IO23 GND)*
- `J17:2` - Sensor-Eingang  *(Hinweis: 5-V-Ausgang GND - Pin 2)*
- `J18:2` - Laden (IP2326, 2S)  *(Hinweis: NTC-Rueckleitung)*
- `J2:1` - Sensor-Eingang  *(Hinweis: Sensor GND)*
- `J5:GND (A1/A12/B1/B12) + Schirm` - USB-C Eingang
- `J6:2` - Taster und LEDs  *(Hinweis: Lotpad/Bohrung - Taster-Rueckleitung)*
- `J7:1` - Lichtsensor  *(Hinweis: Lichtsensor GND)*
- `J8:1` - Erweiterung  *(Hinweis: I2C GND)*
- `J9:1` - Erweiterung  *(Hinweis: Reserve-Analog GND)*
- `Q1:2 Source` - Pumpentreiber
- `Q_PROT2:1 S` - -  *(Hinweis: Source des Lade-MOSFET = Board-GND - traegt den gesamten Systemstrom)*
- `Q_PROT2:2 S` - -
- `Q_PROT2:3 S` - -
- `Q_PUMP2:Source` - -  *(Hinweis: Source AO3400A)*
- `R2:2` - Pumpentreiber
- `R3b:2` - -  *(Hinweis: UVLO-Teiler unten)*
- `R5a:2` - -
- `R5b:2` - -
- `R_FB5_BOT:2` - -
- `R_GATE2_PD:2` - -  *(Hinweis: Pulldown Q3)*
- `R_ISET:2` - -
- `R_LIGHT:2` - -  *(Hinweis: Lastwiderstand Lichtsensor nach GND)*
- `R_NTC_PAR:2` - Laden (IP2326, 2S)
- `R_PROT_CS:2` - -
- `R_SENSE_BOT:2` - -  *(Hinweis: ADC-Teiler unten)*
- `R_UVSET:2` - -
- `SW1:2` - ESP32-C6
- `SW2:2` - ESP32-C6
- `TP3:1` - Akku und Pack  *(Hinweis: Testpad GND)*
- `U1:1` - ESP32-C6  *(Hinweis: Modul-Masse)*
- `U1:11` - ESP32-C6  *(Hinweis: Modul-Masse)*
- `U1:14` - ESP32-C6  *(Hinweis: Modul-Masse)*
- `U1:2` - ESP32-C6  *(Hinweis: Modul-Masse)*
- `U1:36` - ESP32-C6  *(Hinweis: Modul-Masse)*
- `U1:37` - ESP32-C6  *(Hinweis: Modul-Masse)*
- `U1:38` - ESP32-C6  *(Hinweis: Modul-Masse)*
- `U1:39` - ESP32-C6  *(Hinweis: Modul-Masse)*
- `U1:40` - ESP32-C6  *(Hinweis: Modul-Masse)*
- `U1:41` - ESP32-C6  *(Hinweis: Modul-Masse)*
- `U1:42` - ESP32-C6  *(Hinweis: Modul-Masse)*
- `U1:43` - ESP32-C6  *(Hinweis: Modul-Masse)*
- `U1:44` - ESP32-C6  *(Hinweis: Modul-Masse)*
- `U1:45` - ESP32-C6  *(Hinweis: Modul-Masse)*
- `U1:46` - ESP32-C6  *(Hinweis: Modul-Masse)*
- `U1:47` - ESP32-C6  *(Hinweis: Modul-Masse)*
- `U1:48` - ESP32-C6  *(Hinweis: Modul-Masse)*
- `U1:49` - ESP32-C6  *(Hinweis: Modul-Masse)*
- `U1:50` - ESP32-C6  *(Hinweis: Modul-Masse)*
- `U1:51` - ESP32-C6  *(Hinweis: Modul-Masse)*
- `U1:52` - ESP32-C6  *(Hinweis: Modul-Masse)*
- `U1:53` - ESP32-C6  *(Hinweis: Modul-Masse)*
- `U1:EPAD (Pin 49)` - ESP32-C6  *(Hinweis: # Kommentar: EPAD = Pad 49 und damit in U1 Pin 36-53 enthalten; das Symbol hat keinen eigenen EPAD-Pin - keine eigene Verbindung (kein Phantompin))*
- `U6:2 GND` - USB-C Eingang
- `U7:1 GND` - Unterspannungswaechter
- `U_BUCK3:4 GND` - -
- `U_BUCK5:2 GND` - -
- `U_CHG:18 PGND` - -  *(Hinweis: Leistungsmasse des Boost-Laders)*
- `U_CHG:EPAD` - -  *(Hinweis: Thermo-Pad - mit GND verbinden (Datenblatt))*

### `BOOT`

Pins: 3

- `R_BOOT:2` - -
- `SW2:1` - ESP32-C6  *(Hinweis: Taster gegen GND)*
- `U1:23 IO9` - ESP32-C6  *(Hinweis: Strapping - KEIN grosser C)*

### `BST_3V3`

Pins: 2

- `C_B3_BST:1` - -  *(Hinweis: 100 nF Bootstrap)*
- `U_BUCK3:6 BST` - -  *(Hinweis: Bootstrap-Pin)*

### `BST_5V`

Pins: 2

- `C_B5_BST:1` - -  *(Hinweis: 100 nF Bootstrap)*
- `U_BUCK5:1 BS` - -  *(Hinweis: Bootstrap-Pin)*

### `BST_CHG`

Pins: 2

- `C_BST_CHG:1` - -  *(Hinweis: 100 nF Bootstrap (Datenblatt C2))*
- `U_CHG:14 BST` - -

### `BTN`

Pins: 4

- `C_BTN:1` - -  *(Hinweis: 100 nF Entprellung)*
- `J6:1` - Taster und LEDs  *(Hinweis: Lotpad/Bohrung fuer den externen Taster (sitzt im Gehaeuse))*
- `R_BTN:2` - -
- `U1:15 IO6` - ESP32-C6  *(Hinweis: LP_GPIO6 - weckt aus dem Deep-Sleep (EXT1 ANY_LOW))*

### `CC1`

Pins: 2

- `J5:A5 CC1` - USB-C Eingang
- `R5a:1` - -  *(Hinweis: 5.1 kOhm nach GND (USB-C-Senke))*

### `CC2`

Pins: 2

- `J5:B5 CC2` - USB-C Eingang
- `R5b:1` - -  *(Hinweis: 5.1 kOhm nach GND (USB-C-Senke))*

### `EN`

Pins: 4

- `C4:1` - ESP32-C6  *(Hinweis: 1 uF RC-Glied)*
- `R_EN:2` - -
- `SW1:1` - ESP32-C6  *(Hinweis: Taster gegen GND)*
- `U1:8 EN` - ESP32-C6  *(Hinweis: Reset)*

### `EN_CHG`

Pins: 2

- `R_EN_CHG:2` - -  *(Hinweis: Lader-Enable (High = laden))*
- `U_CHG:12 EN` - -  *(Hinweis: EN niemals floaten)*

### `EXT_EN`

Pins: 3

- `Q2:1 Gate` - Erweiterung
- `R_GATE:2` - -
- `U1:26 IO20` - ESP32-C6  *(Hinweis: Load-Switch-Eingang (interner WPU beim Reset))*

### `EXT_SENS_EN`

Pins: 3

- `Q_SENS:1 Gate` - Sensor-Eingang  *(Hinweis: Gate des Sensor-Lastschalters)*
- `R_SENS_GATE:1` - Sensor-Eingang
- `U1:6 IO3` - ESP32-C6  *(Hinweis: Sensor-Lastschalter (low = ein; Pull-up haelt ihn im Reset aus))*

### `FB_5V`

Pins: 3

- `R_FB5_BOT:1` - -  *(Hinweis: Teiler unten 10 k)*
- `R_FB5_TOP:2` - -  *(Hinweis: Teiler oben)*
- `U_BUCK5:3 FB` - -  *(Hinweis: Feedback-Eingang (0,6 V intern))*

### `GATE`

Pins: 3

- `Q1:1 Gate` - Pumpentreiber
- `R1:2` - Pumpentreiber
- `R2:1` - Pumpentreiber  *(Hinweis: 47 kOhm Pulldown)*

### `GATE2`

Pins: 3

- `Q_PUMP2:Gate` - -  *(Hinweis: Gate AO3400A)*
- `R_GATE2:2` - -  *(Hinweis: Gate-Knoten Q3)*
- `R_GATE2_PD:1` - -  *(Hinweis: Pulldown 47 k nach GND)*

### `GPIO8_STRAP`

Pins: 2

- `R_GPIO8:2` - -
- `U1:22 IO8` - ESP32-C6  *(Hinweis: Strapping-Pin)*

### `ISET_CHG`

Pins: 2

- `R_ISET:1` - -  *(Hinweis: 100 kOhm 1 Prozent -> ICHG = 90000/100000 = 0,90 A)*
- `U_CHG:11 ISET` - -  *(Hinweis: ISET darf NICHT offen bleiben (Datenblatt))*

### `LED_CHG`

Pins: 2

- `D_LEDCHG:Anode` - -  *(Hinweis: Lade-LED (leuchtet beim Laden, aus bei Voll, blinkt bei Fehler))*
- `R_LEDCHG:2` - -  *(Hinweis: Knoten zwischen Vorwiderstand und LED-Anode)*

### `LED_STAT`

Pins: 2

- `R4:1` - ESP32-C6  *(Hinweis: 220 Ohm (gruene LED, Vf 2,85 V))*
- `U1:19 IO14` - ESP32-C6  *(Hinweis: Status-LED (NICHT IO4 = MTMS/Strapping))*

### `LED_STAT_A`

Pins: 2

- `D2:Anode` - ESP32-C6  *(Hinweis: LED gruen)*
- `R4:2` - ESP32-C6

### `LED_TANK`

Pins: 2

- `R_TANK:1` - -  *(Hinweis: 1 kOhm)*
- `U1:16 IO7` - ESP32-C6  *(Hinweis: LP_GPIO7 - Tank-leer-Anzeige)*

### `LED_TANK_A`

Pins: 2

- `D5:Anode` - ESP32-C6  *(Hinweis: LED rot)*
- `R_TANK:2` - -

### `LIGHT_AOUT`

Pins: 3

- `C_LIGHT:1` - -  *(Hinweis: 100 nF Filter)*
- `R_LIGHT_S:2` - -
- `U1:9 IO4` - ESP32-C6  *(Hinweis: ADC1_CH4 - Lichtsensor)*

### `LIGHT_RAW`

Pins: 3

- `J7:3` - Lichtsensor  *(Hinweis: Sensorausgang - definierter Zustand bei offenem Stecker)*
- `R_LIGHT:1` - -  *(Hinweis: 10 kOhm Lastwiderstand)*
- `R_LIGHT_S:1` - -  *(Hinweis: 1 kOhm Serienschutz)*

### `LX_3V3`

Pins: 3

- `C_B3_BST:2` - -  *(Hinweis: Bootstrap-Kondensator zwischen BST und SW)*
- `L_BUCK3:1` - -  *(Hinweis: Induktivitaet 4.7 uH - andere Seite an +3V3)*
- `U_BUCK3:5 SW` - -  *(Hinweis: Schaltknoten des 3,3-V-Bucks)*

### `LX_5V`

Pins: 3

- `C_B5_BST:2` - -  *(Hinweis: Bootstrap-Kondensator zwischen BS und LX)*
- `L_BUCK5:1` - -  *(Hinweis: Induktivitaet 4.7 uH - andere Seite an +5V)*
- `U_BUCK5:6 LX` - -  *(Hinweis: Schaltknoten des 5-V-Bucks)*

### `LX_CHG`

Pins: 5

- `C_BST_CHG:2` - -  *(Hinweis: Bootstrap-Kondensator zwischen BST und LX)*
- `L_CHG:2` - -  *(Hinweis: Schaltknoten des Boost-Laders)*
- `U_CHG:15 LX` - -
- `U_CHG:16 LX` - -
- `U_CHG:17 LX` - -

### `MID`

Pins: 3

- `J1:2` - Akku und Pack  *(Hinweis: Mittelabgriff (Zelle 1 + / Zelle 2 -) - erst mit diesem Stecker ist Balancing moeglich)*
- `R_CB:1` - -  *(Hinweis: Balancing-Widerstand zum VBATM-Pin des Laders)*
- `R_PROT_VC:1` - -  *(Hinweis: 330 R zum VC-Pin (Datenblatt-Typwert))*

### `NTC_CHG`

Pins: 3

- `J18:1` - Laden (IP2326, 2S)  *(Hinweis: NTC-Signal vom Akku-Temperatursensor (XH-2P, Gegenstueck am Kabel))*
- `R_NTC_PAR:1` - Laden (IP2326, 2S)  *(Hinweis: 82 k parallel zum NTC - Datenblatt-Wert, legt die Schwellen auf 0 / 45 / 55 Grad C)*
- `U_CHG:4 NTC` - -  *(Hinweis: Akku-NTC (100 kOhm B3950) ueber Stecker J18; 82 k parallel laut Datenblatt-Beispiel)*

### `PROT_COMMON`

Pins: 2

- `Q_PROT1:5 D` - -  *(Hinweis: Gemeinsamer Drain beider Schalter (Symbol-Pin 5 = D, Datenblatt: Montagebasis ist Drain))*
- `Q_PROT2:5 D` - -

### `PROT_CS`

Pins: 2

- `R_PROT_CS:1` - -  *(Hinweis: 2 k zum Board-GND (Datenblatt R3 typ 2 k))*
- `U_PROT:3 CS` - -  *(Hinweis: Strommessung + Ladeerkennung (Datenblatt Pin 3))*

### `PROT_GATE_C`

Pins: 2

- `Q_PROT2:4 G` - -  *(Hinweis: Gate des Lade-MOSFET)*
- `U_PROT:2 OC` - -  *(Hinweis: Lade-Steuerung (Datenblatt Pin 2))*

### `PROT_GATE_D`

Pins: 2

- `Q_PROT1:4 G` - -  *(Hinweis: Gate des Entlade-MOSFET (Pin 4 = Gate))*
- `U_PROT:1 OD` - -  *(Hinweis: Entlade-Steuerung (Datenblatt Pin 1))*

### `PROT_VC`

Pins: 3

- `C_PROT_VC:1` - -  *(Hinweis: 0)*
- `R_PROT_VC:2` - -
- `U_PROT:4 VC` - -  *(Hinweis: Mittelabgriff-Messung (Datenblatt Pin 4))*

### `PROT_VDD`

Pins: 3

- `C_PROT_VDD:1` - -  *(Hinweis: 0)*
- `R_PROT_VDD:2` - -
- `U_PROT:5 VDD` - -  *(Hinweis: Versorgung (Datenblatt Pin 5))*

### `PUMP2_EN`

Pins: 2

- `R_GATE2:1` - -  *(Hinweis: Gate-Serie 1 kOhm (Kanal 2))*
- `U1:28 IO22` - ESP32-C6  *(Hinweis: Gate-Steuersignal Sauerstoffpumpe)*

### `PUMP2_N`

Pins: 4

- `C_PUMP2_EMI:1` - -  *(Hinweis: 100 nF an den Klemmen nach GND)*
- `D_FLY2:Anode` - -  *(Hinweis: Freilaufdiode)*
- `J16:2` - Pumpentreiber  *(Hinweis: Sauerstoffpumpe - (Pin 2))*
- `Q_PUMP2:Drain` - -  *(Hinweis: geschaltete Masse Sauerstoffpumpe)*

### `PUMP_EN`

Pins: 2

- `R1:1` - Pumpentreiber  *(Hinweis: Gate-Serie 1 kOhm (schnelle Flanken fuer PWM))*
- `U1:5 IO2` - ESP32-C6  *(Hinweis: Pumpen-PWM)*

### `PUMP_N`

Pins: 4

- `C11:1` - Pumpentreiber  *(Hinweis: 100 nF direkt an den Pumpenklemmen (Buerstenstoerung))*
- `D1:Anode` - Pumpentreiber
- `J4:2` - Pumpentreiber  *(Hinweis: Pumpe -)*
- `Q1:3 Drain` - Pumpentreiber  *(Hinweis: Low-Side-Schalter)*

### `RESET_UV`

Pins: 2

- `U7:2 RESET` - Unterspannungswaechter  *(Hinweis: Push-Pull aktiv-low; 200 ms Verzoegerung nach dem Anlaufen)*
- `U_BUCK5:4 EN` - -  *(Hinweis: unter 6,16 V schaltet die 5-V-Schiene wirklich ab (Buck: EN low = 0 V))*

### `SCL`

Pins: 3

- `J8:4` - Erweiterung  *(Hinweis: I2C-Takt (Steckerseite))*
- `R_SCL_PU:1` - -  *(Hinweis: 4.7 kOhm Pull-up nach VCC_EXT)*
- `R_SCL_S:2` - -  *(Hinweis: 1 kOhm Serienschutz)*

### `SCL_MCU`

Pins: 2

- `R_SCL_S:1` - -
- `U1:25 IO19` - ESP32-C6  *(Hinweis: I2C-Takt am Modul)*

### `SDA`

Pins: 3

- `J8:3` - Erweiterung  *(Hinweis: I2C-Daten (Steckerseite))*
- `R_SDA_PU:1` - -  *(Hinweis: 4.7 kOhm Pull-up nach VCC_EXT)*
- `R_SDA_S:2` - -  *(Hinweis: 1 kOhm Serienschutz)*

### `SDA_MCU`

Pins: 2

- `R_SDA_S:1` - -
- `U1:24 IO18` - ESP32-C6  *(Hinweis: I2C-Daten am Modul)*

### `SENSOR_AOUT`

Pins: 4

- `C9:1` - ESP32-C6  *(Hinweis: 100 nF Filter)*
- `R6:2` - Sensor-Eingang
- `TP6:1` - Sensor-Eingang  *(Hinweis: Testpad SENSOR_AOUT)*
- `U1:12 IO0` - ESP32-C6  *(Hinweis: ADC1_CH0)*

### `SENSOR_PWR`

Pins: 3

- `J2:2` - Sensor-Eingang  *(Hinweis: Sensor VCC (Feuchte))*
- `J7:2` - Lichtsensor  *(Hinweis: Lichtsensor VCC (extern, geschaltet))*
- `Q_SENS:3 Drain` - Sensor-Eingang  *(Hinweis: geschaltete Sensorversorgung (Feuchte J2 + Licht J7))*

### `SENSOR_RAW`

Pins: 2

- `J2:3` - Sensor-Eingang  *(Hinweis: Sensor AOUT unbeschaltet)*
- `R6:1` - Sensor-Eingang  *(Hinweis: 1 kOhm Serienwiderstand)*

### `SPARE_AIN`

Pins: 3

- `C_SPARE:1` - -  *(Hinweis: 100 nF ADC-Filter)*
- `R_SPARE_AIN:2` - -
- `U1:10 IO5` - ESP32-C6  *(Hinweis: ADC1_CH5)*

### `SPARE_AIN_RAW`

Pins: 2

- `J9:3` - Erweiterung  *(Hinweis: Reserve-Analog am Stecker)*
- `R_SPARE_AIN:1` - -

### `SPARE_IO15`

Pins: 2

- `R_SPARE_IO15:2` - -
- `U1:20 IO15` - ESP32-C6  *(Hinweis: Strapping JTAG-Quelle (Default-eFuses inert))*

### `SPARE_IO15_RAW`

Pins: 2

- `J10:3` - Erweiterung  *(Hinweis: Reserve IO15 am Stecker)*
- `R_SPARE_IO15:1` - -

### `SPARE_IO16`

Pins: 2

- `J11:3` - Erweiterung
- `R_SPARE_IO16:2` - -  *(Hinweis: Reserve IO16 (TXD0) am Stecker)*

### `SPARE_IO17`

Pins: 2

- `J12:3` - Erweiterung
- `R_SPARE_IO17:2` - -  *(Hinweis: Reserve IO17 (RXD0) am Stecker)*

### `SPARE_IO21`

Pins: 2

- `R_SPARE_IO21:2` - -
- `U1:27 IO21` - ESP32-C6  *(Hinweis: WPU beim Reset (angehaengtes Modul sieht kurz High))*

### `SPARE_IO21_RAW`

Pins: 2

- `J13:3` - Erweiterung  *(Hinweis: Reserve IO21 am Stecker)*
- `R_SPARE_IO21:1` - -

### `SPARE_IO23`

Pins: 2

- `R_SPARE_IO23:2` - -
- `U1:29 IO23` - ESP32-C6

### `SPARE_IO23_RAW`

Pins: 2

- `J15:3` - Erweiterung  *(Hinweis: Reserve IO23 am Stecker)*
- `R_SPARE_IO23:1` - -

### `STAT_CHG`

Pins: 2

- `D_LEDCHG:Kathode` - -  *(Hinweis: Kathode an den LED-Pin des Laders (Senke, max. 5 mA))*
- `U_CHG:6 LED` - -  *(Hinweis: LED-Senke max. 5 mA)*

### `UART_RX`

Pins: 3

- `R_SPARE_IO17:1` - -  *(Hinweis: 1 kOhm Serienschutz zum Reserve-Stecker)*
- `TP2:1` - ESP32-C6  *(Hinweis: Testpad RXD0)*
- `U1:30 RXD0` - ESP32-C6  *(Hinweis: IO17 - optional DNP)*

### `UART_TP`

Pins: 2

- `R_UART:2` - -
- `TP1:1` - UART-Debug-Pads (DNP)  *(Hinweis: Testpad TXD0)*

### `UART_TX`

Pins: 3

- `R_SPARE_IO16:1` - -  *(Hinweis: 1 kOhm Serienschutz zum Reserve-Stecker)*
- `R_UART:1` - -  *(Hinweis: 499 Ohm)*
- `U1:31 TXD0` - ESP32-C6  *(Hinweis: IO16 - optional DNP)*

### `USB_DM`

Pins: 4

- `J5:D- (A7/B7)` - USB-C Eingang
- `U1:17 IO12` - ESP32-C6  *(Hinweis: USB D-)*
- `U6:3 I/O2` - USB-C Eingang  *(Hinweis: ESD)*
- `U6:4 I/O2` - USB-C Eingang  *(Hinweis: ESD durchgeschleift)*

### `USB_DP`

Pins: 4

- `J5:D+ (A6/B6)` - USB-C Eingang
- `U1:18 IO13` - ESP32-C6  *(Hinweis: USB D+)*
- `U6:1 I/O1` - USB-C Eingang  *(Hinweis: ESD)*
- `U6:6 I/O1` - USB-C Eingang  *(Hinweis: ESD durchgeschleift)*

### `UVSET_CHG`

Pins: 2

- `R_UVSET:1` - -  *(Hinweis: 68 kOhm -> Eingangs-Unterspannungsschwelle 4,35 V)*
- `U_CHG:8 VIN_UVSET` - -  *(Hinweis: mehr Kopfraum fuer duenne USB-Kabel bei ~1,8 A Eingangsstrom)*

### `UV_REF`

Pins: 4

- `C12:1` - Unterspannungswaechter  *(Hinweis: 100 nF Decoupling am Waechter (Datenblatt-Messbedingung C1 = 0,1 uF))*
- `R3a:2` - -  *(Hinweis: Teilerknoten = Versorgung des Waechters (VBAT/2))*
- `R3b:1` - -  *(Hinweis: Teiler unten 51 k)*
- `U7:3 VDD` - Unterspannungswaechter  *(Hinweis: Schwelle 3,08 V -> Ausloesung bei VBAT = 6,16 V (plus ~30 mV Offset durch Iq))*

### `VBATM_CHG`

Pins: 2

- `R_CB:2` - -
- `U_CHG:23 VBATM` - -  *(Hinweis: Balancing-Ausgang (Datenblatt Pin 23))*

### `VBAT_SENSE`

Pins: 4

- `C10:1` - ESP32-C6  *(Hinweis: 100 nF Filter)*
- `R_SENSE_BOT:1` - -
- `R_SENSE_TOP:2` - -  *(Hinweis: Teilerknoten)*
- `U1:13 IO1` - ESP32-C6  *(Hinweis: ADC1_CH1 - 8,4 V ergeben 2,13 V am ADC (12-dB-Bereich 0-3300 mV))*

## 4. Wo ist was

Die Blockaufteilung (14 Rahmen auf Blatt A1) und ihre Koordinaten stammen aus der EasyEDA-Kette
und werden im naechsten Durchgang neu erzeugt - nach den Aenderungen dieser Runde (entfallene
Feedback- und Klemmbauteile, neue Bauteile F1/J18/R_NTC_PAR/Q_SENS/R_SENS_GATE) ist der alte Plan
nicht mehr aktuell.

## 5. Anschluesse

### J1 - Akku JST-XH 3P (B-/MID/B+), aufrecht

| Pin | Netz |
|---|---|
| 1 | BAT_MINUS |
| 2 | MID |
| 3 | PACK_PLUS |

### J2 - Feuchtesensor JST-XH 3P, aufrecht

| Pin | Netz |
|---|---|
| 1 | GND |
| 2 | SENSOR_PWR |
| 3 | SENSOR_RAW |

### J4 - Dosierpumpe JST-XH 2P, aufrecht

| Pin | Netz |
|---|---|
| 1 | +5V |
| 2 | PUMP_N |

### J5 - USB-C 16P Buchse (Laden + Programmieren)

| Pin | Netz |
|---|---|
| A5 CC1 | CC1 |
| B5 CC2 | CC2 |
| D+ (A6/B6) | USB_DP |
| D- (A7/B7) | USB_DM |
| VBUS (A4/A9/B4/B9) | VBUS |
| GND (A1/A12/B1/B12) + Schirm | GND |

### J6 - 2 Loetpads externer Taster

| Pin | Netz |
|---|---|
| 1 | BTN |
| 2 | GND |

### J7 - Lichtsensor-Stiftleiste 1x3 2,54 mm

| Pin | Netz |
|---|---|
| 1 | GND |
| 2 | SENSOR_PWR |
| 3 | LIGHT_RAW |

### J8 - I2C-Stiftleiste 1x4 (GND-VCC-SDA-SCL)

| Pin | Netz |
|---|---|
| 1 | GND |
| 2 | VCC_EXT |
| 3 | SDA |
| 4 | SCL |

### J9 - Reserve-Analog Stiftleiste 1x3 (IO5)

| Pin | Netz |
|---|---|
| 1 | GND |
| 2 | VCC_EXT |
| 3 | SPARE_AIN_RAW |

### J10 - Reserve IO15 Stiftleiste 1x3

| Pin | Netz |
|---|---|
| 1 | GND |
| 2 | VCC_EXT |
| 3 | SPARE_IO15_RAW |

### J11 - Reserve IO16 (TXD0) Stiftleiste 1x3

| Pin | Netz |
|---|---|
| 1 | GND |
| 2 | VCC_EXT |
| 3 | SPARE_IO16 |

### J12 - Reserve IO17 (RXD0) Stiftleiste 1x3

| Pin | Netz |
|---|---|
| 1 | GND |
| 2 | VCC_EXT |
| 3 | SPARE_IO17 |

### J13 - Reserve IO21 Stiftleiste 1x3

| Pin | Netz |
|---|---|
| 1 | GND |
| 2 | VCC_EXT |
| 3 | SPARE_IO21_RAW |

### J15 - Reserve IO23 Stiftleiste 1x3

| Pin | Netz |
|---|---|
| 1 | GND |
| 2 | VCC_EXT |
| 3 | SPARE_IO23_RAW |

### J16 - Sauerstoffpumpe JST-XH 2P, aufrecht

| Pin | Netz |
|---|---|
| 1 | +5V |
| 2 | PUMP2_N |

### J17 - 5-V-Ausgang fuer Sensorik JST-XH 2P

| Pin | Netz |
|---|---|
| 1 | +5V |
| 2 | GND |

### J18 - Stecker fuer den Akku-Temperatursensor (XH-2P, 1 = NTC-Signal, 2 = GND)

| Pin | Netz |
|---|---|
| 1 | NTC_CHG |
| 2 | GND |

### Testpunkte

| Ref | Netz |
|---|---|
| TP1 | (frei) |
| TP2 | (frei) |
| TP3 | (frei) |
| TP4 | (frei) |
| TP5 | (frei) |
| TP6 | (frei) |

## 6. MCU-Pinbelegung (U1, ESP32-C6-MINI-1)

| Pin | Symbolname | Netz |
|---|---|---|
| 1 | GND | GND |
| 2 | GND | GND |
| 3 | 3V3 | +3V3 |
| 5 | IO2 | PUMP_EN |
| 6 | IO3 | EXT_SENS_EN |
| 8 | EN | EN |
| 9 | IO4 | LIGHT_AOUT |
| 10 | IO5 | SPARE_AIN |
| 11 | GND | GND |
| 12 | IO0 | SENSOR_AOUT |
| 13 | IO1 | VBAT_SENSE |
| 14 | GND | GND |
| 15 | IO6 | BTN |
| 16 | IO7 | LED_TANK |
| 17 | IO12 | USB_DM |
| 18 | IO13 | USB_DP |
| 19 | IO14 | LED_STAT |
| 20 | IO15 | SPARE_IO15 |
| 22 | IO8 | GPIO8_STRAP |
| 23 | IO9 | BOOT |
| 24 | IO18 | SDA_MCU |
| 25 | IO19 | SCL_MCU |
| 26 | IO20 | EXT_EN |
| 27 | IO21 | SPARE_IO21 |
| 28 | IO22 | PUMP2_EN |
| 29 | IO23 | SPARE_IO23 |
| 30 | RXD0 | UART_RX |
| 31 | TXD0 | UART_TX |
| 36 | GND | GND |
| 37 | GND | GND |
| 38 | GND | GND |
| 39 | GND | GND |
| 40 | GND | GND |
| 41 | GND | GND |
| 42 | GND | GND |
| 43 | GND | GND |
| 44 | GND | GND |
| 45 | GND | GND |
| 46 | GND | GND |
| 47 | GND | GND |
| 48 | GND | GND |
| 49 | GND | GND |
| 50 | GND | GND |
| 51 | GND | GND |
| 52 | GND | GND |
| 53 | GND | GND |
| VDD33 | (alle) | +3V3 |
| EPAD | (Pin 49) | GND |

## 7. Betriebs- und Randbedingungen

### 7.1 Protokoll der Design-Pruefsuite (gerechnete Werte gegen Grenzwerte)

```
Pruefungen: 42
----------------------------------------------------------------------------------------------------
#  Pruefung                     Ergebnis Ist                                Soll
----------------------------------------------------------------------------------------------------
1  Ladestrom IP2326             OK       0,90 A (R_ISET 100 kΩ)             <= 1,5 A und <= 1 C = 2,00 A
   Begruendung: IP2326-Datenblatt V1.11: ICHG = 90000/R_ISET[Ohm] (S. 11); Grenze 1,5 A (§7, S. 4); ISET darf nicht offen bleiben (§4); Li-Ion erlaubt 1 C (Review §4.1)
2  Ladeschluss 2S               OK       8,40 V (2 x 4,2 V), VSET offen, CON_SEL offen, 8V8 im BOM nein 8,4 V +-0,1 V, VSET/CON_SEL offen, kein IP2326_8V8
   Begruendung: IP2326 S. 4/S. 5: VSET offen ⇒ 8,4 V (8,3-8,5 V) = 4,2 V/Zelle, CON_SEL offen ⇒ 2S (S. 8); IP2326_8V8 waere 8,8 V (4,4 V/Zelle) und fuer Li-Ion unzulaessig
3  Ladeeingangsstrom            OK       2,21 A (Ladung 1,61 A + System 0,60 A) <= 2,5 A (Netzteilannahme)
   Begruendung: IP2326 S. 1: eta 94 % (5 V->8 V/1 A); I_in = V_out*I_CHG/(eta*V_USB) + Systemlast (beide Pumpen, schaltplan §6.1)
4  5-V-Buck-Ausgang             OK       5,100 V (+-5 % von 5,0 V)          5,0 V +-5 %
   Begruendung: SY8113B-Datenblatt S. 1/S. 2: V_REF 0,6 V +-1,5 %, V_out = 0,6 x (1 + R_FB5_TOP/R_FB5_BOT); Pumpennennspannung 5 V
5  3,3-V-Buck-Ausgang           OK       3,300 V (FB Pin 1 auf +3V3 OK, Teiler keiner, Netz FB_3V3 entfallen) 3,0 V bis 3,6 V (Modul); FB direkt auf +3V3, kein Teiler
   Begruendung: AP63203-Datenblatt DS41326: Festspannungsversion, VFB 3,27/3,30/3,33 V bzw. 'AP63203 ... fixed output voltages of 3.3V'; Fig. 21 fuehrt FB direkt auf den Ausgang. Der frueher geprüfte Teiler R_FB3_TOP/BOT ist entfallen (Review 16.09.2026); Espressif ESP32-C6-MINI-1: V_DD33 3,0-3,6 V
6  5-V-Buck-Induktivitaet       OK       4,7 µH (I_Last 3,0 A, Isat 4,0 A); Vin 8,40 V: dI 0,85 A, I_peak 3,43 A; Vin 6,17 V: dI 0,38 A, I_peak 3,19 A I_peak < Isat 4,0 A und I_Last <= 3 A
   Begruendung: PRS6045-Datenblatt: L_BUCK5 4,7 µH, Isat 4,0 A; SY8113B S. 1: 3 A, 500 kHz; dI = (Vin-Vout)*D/(L*f) mit D = Vout/Vin; I_Last = Pumpenanlauf 3 A (bom §4c)
7  3,3-V-Buck-Induktivitaet     OK       4,7 µH (I_Last TX-Peak 0,382 A, Isat 4,0 A); Vin 8,40 V: dI 0,39 A, I_peak 0,58 A; Vin 6,17 V: dI 0,30 A, I_peak 0,53 A I_peak < Isat 4,0 A
   Begruendung: PRS6045-Datenblatt: L_BUCK3 4,7 µH, Isat 4,0 A; AP63203 DS41326: 2 A, 1,1 MHz; I_Last = Modul-TX-Peak 382 mA (Espressif Tab. 6-4)
8  UVLO-Schwelle                OK       6,168 V (V_IT 3,08 V, R3a 51 kΩ, Iq 0,15 µA) 6,0 V bis 6,6 V Pack (2 x 3,0..3,3 V)
   Begruendung: TPS3839 S. 7: V_IT 3,003-3,126 V, Hysterese 31 mV; V_trip = V_IT x (1 + R3a/R3b) + Iq x R3a (Teiler 51 k/51 k, Iq typ. 0,15 µA bzw. max. 0,5 µA)
9  UV-Teiler-Offset             OK       R3a 51 kΩ/51 kΩ, Teilerstrom 82,4 µA (1,98 mAh/Tag), Offset Iq_max x R3a = 25,5 mV (typ. 7,6 mV) R3a = R3b = 51 kΩ, Iq-Offset <= 50 mV, Teilerstrom <= 100 µA
   Begruendung: Fix 16.09.2026 (Review): von 200 k/200 k auf 51 k/51 k verkleinert. TPS3839-Datenblatt SBVS193D: Iq 150 nA typ., 500 nA max.; der Strom fließt durch R3a und verschiebt die Schwelle um Iq x R3a (200 k waeren bis ~0,2 V gewesen, jetzt +15..+50 mV). Teilerstrom 82 µA = ~2 mAh/Tag, Teil des 250-µA-Standby-Budgets (schaltplan §3.2/§13.5)
10 Gate-Pulldowns               OK       R2 47 kΩ an GATE/GND OK; R_GATE2_PD 47 kΩ an GATE2/GND OK; Gate-Serie R1/R_GATE2 OK R2 (GATE/GND) und R_GATE2_PD (GATE2/GND) je 47 kΩ; Gates ueber Serien-R1/R_GATE2 von der MCU
   Begruendung: Review 16.09.2026: der alte Dioden-Klemmzweig (D3/D8 + R_CLAMP1/2) konnte das Gate gegen den 1-kΩ-GPIO-Zweig rechnerisch nicht abschalten (~2,97 V) und ist entfallen. Wirksam bleiben (a) die 5-V-Abschaltung durch U7 und (b) diese 47-kΩ-Pulldowns: bei hochohmigem GPIO liegt V_GS = 0 V, der MOSFET sperrt
11 ADC-Teiler Packspannung      OK       8,4 V -> 2,131 V, 6,0 V -> 1,522 V (V_ref 3,30 V) <= 3,3 V und >= 1,0 V
   Begruendung: Espressif ESP32-C6 ADC1: 12 Bit, ADC_ATTEN_DB_12 = 0..3300 mV; V_ADC = VBAT x R_bot/(R_top+R_bot), Teiler 200 k/68 k
12 Buck-EN-Pegel                OK       V_OH 2,68 V (V_DD 3,08 V - 0,4 V)  > 1,5 V (EN High)
   Begruendung: TPS3839 SBVS193D: V_OH >= V_DD - 0,4 V (Push-Pull); SY8113B: EN-High-Schwelle 1,5 V, 'Do not float'
13 Waechter-Abschaltung         OK       U7 Pin 2 (RESET) auf RESET_UV, U_BUCK5 Pin 4 (EN) auf RESET_UV OK; Klemmzweig-Rest keiner  U7-RESET und U_BUCK5-EN auf RESET_UV; kein D3/D8/R_CLAMP*/KLAMP*
   Begruendung: TPS3839 SBVS193D: Push-Pull-Ausgang aktiv-low; SY8113B: EN low => Ausgang 0 V. Damit ist die Pumpenversorgung im Waechterfall sicher aus. Der Dioden-Klemmzweig D3/D8/R_CLAMP1/2 ist im Review 16.09.2026 als wirkungslos entfernt worden (§13.5)
14 VBAT-Spannungsfestigkeit     OK       13 Teilnehmer: C_B3_IN, C_B3_IN_HF, C_B5_IN, C_B5_IN_HF, C_CHG_OUT, F1, R3a, R_PROT_VDD, R_SENSE_TOP, TP4, U_BUCK3, U_BUCK5, U_CHG nur zugelassene Teilnehmer, V_IN,max >= 8,4 V
   Begruendung: ME6211-Lektion (V_IN,max 6,0 V) aus Review §5 Befund 4: passive VBAT-Teilnehmer sind gelistet, aktive werden gegen ihre Datenblatt-Eingangsspannung geprueft (IP2326 9,5 V, SY8113B 18 V, AP63203 32 V)
15 Standby-Budget               OK       242,8 µA, 5,83 mAh/Tag; Lichtsensor an SENSOR_PWR geschaltet <= 250 µA; Sensor an SENSOR_PWR (ueber Q_SENS geschaltet)
   Begruendung: Datenblaetter: SY8113B Iq 100 µA, AP63203 22 µA, TPS3839 0,15 µA (schaltplan §6.2) + Teiler 82/31,4 µA (§13.5) + Modul 7 µA; Lichtsensor an geschaltetem SENSOR_PWR, das Gate treibt IO3
16 Systemquellen                OK       22 Systemwerte belegt              jeder SYSTEM-Wert hat sein woertliches Belegfragment in der Datei
   Begruendung: Regel: Systemgroessen stammen ausschliesslich aus den Dokumenten. Prueft fuer jeden Eintrag den Belegtext in schaltplan_v1.md bzw. bom_entscheidung.md
17 Schutz-Serienkette           OK       Pack-Minus J1.1/Q_PROT1-S/U_PROT-VSS OK; Drains beider auf einem Netz (PROT_COMMON) OK; Q_PROT2-S auf GND OK; OD an Q_PROT1-Gate, OC an Q_PROT2-Gate (kein Tausch) OK; R_PROT_CS CS<->GND OK; R_PROT_VDD VDD<->VBAT OK; R_PROT_VC VC<->MID OK; R_CB VBATM<->MID OK; U_CHG.24 auf BAT_MINUS OK; Schalterpaar nicht auf GND OK (Netze: J1-1 BAT_MINUS, Q_PROT1-S BAT_MINUS, Drains PROT_COMMON/PROT_COMMON, Q_PROT2-S GND, OD PROT_GATE_D, OC PROT_GATE_C, U_CHG-24 BAT_MINUS) J1-1 = Q_PROT1-S = U_PROT-VSS (BAT_MINUS), beide Drains auf PROT_COMMON, Q_PROT2-S auf GND, OD nur an Q_PROT1-Gate (Entlader, packseitig), OC nur an Q_PROT2-Gate, R_PROT_CS CS<->GND, R_PROT_VDD VDD<->VBAT, R_PROT_VC VC<->MID, R_CB VBATM<->MID, U_CHG-24 auf BAT_MINUS; Schalterpaar nicht auf GND
   Begruendung: Regressionsschutz der Topologie (Review 16.09.2026): der Schutz sitzt in der Minusleitung zwischen Pack-Minus (BAT_MINUS) und Board-GND. Q_PROT1 (Entlader, Gate an OD) liegt packseitig, Q_PROT2 (Lader, Gate an OC) an GND, gemeinsamer Drain PROT_COMMON. Wird ein Source auf GND gelegt oder OD/OC getauscht, ist der Schutz wirkungslos bzw. die Entlade-/Ladetrennung vertauscht
18 Schutz-Schwellen             OK       Ueberladung 4,28 V/Zelle = 8,56 V Pack (8,4 V < x < 8,8 V) OK; Tiefentladung 2,90 V/Zelle = 5,80 V Pack (5,0 V < x < Waechter 6,17 V) OK; Staffelung FW 6,80 V > Waechter 6,17 V > Zelle 5,80 V OK; Dokument konsistent Ueberladung ja/Tiefentladung ja 8,4 V (Ladeschluss) < Ueberladung Pack < 8,8 V; 5,0 V (2 x 2,5 V Zelle) < Tiefentladung Pack < Waechter 6,19 V; FW-Stopp 6,8 V > Waechter > Zelle 5,80 V
   Begruendung: HY2120-Datenblatt (schaltplan §3.1/§6.3): Ueberladung 4,28 V/Zelle, Tiefentladung 2,90 V/Zelle, jeweils woertlich aus dem Dokument gelesen; Ladeschluss IP2326 8,4 V (VSET offen) bzw. 8,8 V der verbotenen 8V8-Variante; Waechter aus den echten R3a/R3b (TPS3839 V_IT 3,08 V); Firmware-Stopp 2 x 3,4 V (bom §4b). Ueberladung muss das normale Laden ueberleben, Tiefentladung vor dem Waechter greifen
19 Schutz-Ueberstrom            OK       Ausloesung 200 mV / Paar 11,4 mΩ = 17,5 A; Anlauf 15,0 W/(0,90 x 6,0 V) = 2,78 A (Reserve 6,3 x) OK; Abfall bei 0,65 A = 7,4 mV OK; Dokument konsistent ja/ja Ausloesestrom >= 2 x Anlaufstrom und Abfall des Paares bei Dauerlast <= 50 mV
   Begruendung: HY2120-Datenblatt: V_DIP 200 mV (+-30 mV) ueber dem Paar (schaltplan §3.1); PSMN4R2-30MLDX: R_DS(on,max) 5,7 mOhm bei V_GS 4,5 V => Paar 11,4 mOhm (schaltplan §6.3); Pumpenanlauf 5 V/3 A = 15,0 W an 6,0 V Pack ueber eta_Buck 0,90 (bom §4c: eta 0,90), Dauerlast 0,65 A (schaltplan §6.3); die interne Verzoegerung von 10 ms schuetzt den kurzzeitigen Anlauf
20 Gate-Spannung                OK       3,23 V (98 % von 3,30 V)           >= 2,5 V und > 1,45 V
   Begruendung: AO3400A-Datenblatt: RDS(on) bei VGS = 2,5 V spezifiziert, VGS(th) max = 1,45 V; Rail +3V3 aus dem AP63203 in der Festspannungsversion
21 MOSFET-Verlustleistung       OK       7,7 mW (I 400 mA, RDS(on) 48 mΩ)   <= 0,25 W (Nennbetrieb)
   Begruendung: AO3400A-Datenblatt: 48 mΩ bei VGS = 2,5 V; P = I_pump² · RDS(on); I_pump = 0,4 A (Pumpennennstrom); der 3-A-Anlauf ist transient (~100 ms, Review §4.4)
22 Freilaufdiode                OK       I 400 mA (<= 50 % von 1,0 A), VRRM 40 V (>= 4 x 8,4 V) I_pump <= 0,5 A und VRRM >= 4 x VBAT_max (8,4 V)
   Begruendung: 1N5819WS-Datenblatt: 1 A / 40 V; Stromreserve und Spannungsreserve fuer die Induktivitaet der Pumpe (Freilauf gegen +5V)
23 Teilerstrom                  OK       Waechter 82,4 µA + ADC 31,3 µA = 113,7 µA bei 8,4 V <= 130 µA (beide Teiler zusammen)
   Begruendung: Teiler duerfen im Standby-Budget (250 µA) nur ein Teilbudget verbrauchen; I = VBAT_max/(R_top+R_bot) je Teiler. Seit dem UV-Teiler-Fix 16.09.2026 (51 k/51 k) zieht der Waechterteiler ~82 µA statt 21 µA -- die Obergrenze ist entsprechend angehoben (Waechter + ADC = ~113 µA, schaltplan §3.2/§13.5)
24 Unterspannungsstaffelung     OK       Firmware 6,80 V > Waechter 6,17 V > PCM 5,0 V Firmware > TPS3839 (6,16 V) > PCM
   Begruendung: Firmware stoppt zuerst, dann Hardware, zuletzt die Zelle. 1S-Schwellen aus bom §4b (3,4 V / 2,5 V) auf 2S = x2 gerechnet (Auftrag in schaltplan §4)
25 ADC-Filter                   OK       R6·C9 0,10 ms, (R_SENSE_TOP||BOT)·C10 5,1 ms, R_SPARE_AIN·C_SPARE 0,10 ms R6·C9 <= 5 ms, (R_SENSE_TOP||BOT)·C10 <= 50 ms und R_SPARE_AIN·C_SPARE <= 5 ms
   Begruendung: Espressif-ADC: 0,1 µF Filter; Zeitkonstante begrenzt das Einschwingen (Packteiler jetzt R_SENSE_TOP/BOT statt R3a/R3b)
26 Licht-ADC-Filter             OK       R_LIGHT_S·C_LIGHT 0,100 ms (R 1,0 kΩ, C 100 nF) R_LIGHT_S·C_LIGHT <= 5 ms
   Begruendung: Espressif-ADC: 0,1 µF Filter; die Zeitkonstante begrenzt das Einschwingen (gleiche Grenze wie R6·C9)
27 Licht-Kontrast               OK       dunkel 1,2 Counts, bei 10000 lx 4095 Counts (Spanne 4094, Saettigung ab 2200 lx) dunkel <= 200, hell >= 3000, Spanne > 2 x 300 Counts
   Begruendung: ALS-PT19-Datenblatt: ICEO <= 0,1 µA (dunkel), 15 µA typ @ 100 lx; R_LIGHT 10 kΩ; ADC_ATTEN_DB_12 (0-3300 mV, 12 Bit)
28 Licht-Stecker offen          OK       R_LIGHT LIGHT_RAW/GND OK, R_LIGHT_S in Reihe OK, C_LIGHT LIGHT_AOUT/GND OK, J7-3 auf LIGHT_RAW OK, ADC IO4 OK (Pfad nach GND ueber 11 kΩ) R_LIGHT LIGHT_RAW->GND, R_LIGHT_S LIGHT_RAW->LIGHT_AOUT, C_LIGHT LIGHT_AOUT->GND, J7 Pin 3 auf LIGHT_RAW, ADC = IO4
   Begruendung: offener Stecker: R_LIGHT zieht LIGHT_RAW auf 0 V, ueber R_LIGHT_S liegt der ADC auf 0 V -> kein schwebender Eingang
29 LED-Stroeme                  OK       Status (Vf 2,85 V, R4 220 Ω) 2,05 mA, Laden (Vf 2,00 V, R_LEDCHG 1,0 kΩ) 3,00 mA Status- und Lade-LED <= 5 mA
   Begruendung: I = (U - Vf)/R; D2 gruen Vf 2,85 V ueber R4 an +3V3, D_LEDCHG rot Vf 2,0 V ueber R_LEDCHG an VBUS 5 V
30 Tank-LED                     OK       1,30 mA bei Vf 2,0 V (R_TANK 1,0 kΩ) I <= 5 mA, Vf rot ca. 2,0 V
   Begruendung: LED-Vorwiderstand R_TANK an +3V3; D5 und D_LEDCHG sind die roten 0805-LEDs (Vf 2,0 V), D2 ist die gruene
31 LED-Headroom                 OK       D2 (Vf 2,85 V): Headroom 0,45 V OK, 2,05 mA OK; D_LEDCHG (Vf 2,00 V): Headroom 1,30 V OK, 3,00 mA OK; D5 (Vf 2,00 V): Headroom 1,30 V OK, 1,30 mA OK je LED 3,3 V - Vf >= 0,3 V und 0,5-5 mA
   Begruendung: 3,3-V-Rail-Headroom (aus dem AP63203-Feedback) und Stromfenster je LED; Strom aus der jeweiligen Versorgung (D_LEDCHG an 5 V VBUS)
32 Taster-Pullup                OK       BTN: R_BTN 10,0 kΩ +3V3-BTN, C_BTN 0,1 µF BTN-GND, R·C 1,00 ms R_BTN an +3V3/BTN, C_BTN an BTN/GND, 0,5-20 ms
   Begruendung: R_BTN zieht den offenen Taster auf High, C_BTN entprellt; Zeitkonstante lang genug zum Entprellen, kurz genug zum Wecken
33 Taster-Weckquelle            OK       U1 Pin 15 = IO6                    LP-GPIO (IO0-IO7) und kein Strapping-Pin
   Begruendung: Espressif ESP32-C6: LP-GPIOs IO0-IO7 wecken per EXT1; IO6 ist kein Strapping-Pin
34 Pin-Disziplin                OK       Licht 9 IO4, Pumpe 5 IO2, boot-kritisch Licht nein/Pumpe nein, Doppelbelegung keine Licht = IO4 (Pin 9, ADC1_CH4), Pumpe = IO2 (Pin 5), kein boot-kritischer Strapping-Pin (GPIO8/9/15), kein Pin doppelt
   Begruendung: ESP32-C6: boot-kritisch nur GPIO8/GPIO9 (Boot-Modus) und GPIO15 (JTAG-Quelle); IO4/IO5 sind nur SDIO-Strap und als ADC nutzbar
35 Stecker-Pinordnung           OK       J10: 1=GND 2=VCC_EXT 3=SPARE_IO15_RAW OK; J11: 1=GND 2=VCC_EXT 3=SPARE_IO16 OK; J12: 1=GND 2=VCC_EXT 3=SPARE_IO17 OK; J13: 1=GND 2=VCC_EXT 3=SPARE_IO21_RAW OK; J15: 1=GND 2=VCC_EXT 3=SPARE_IO23_RAW OK; J2: 1=GND 2=SENSOR_PWR 3=SENSOR_RAW OK; J7: 1=GND 2=SENSOR_PWR 3=LIGHT_RAW OK; J9: 1=GND 2=VCC_EXT 3=SPARE_AIN_RAW OK; J8: 1=GND 2=VCC_EXT 3=SDA 4=SCL OK Pin 1 = GND, Pin 2 = Versorgung (SENSOR_PWR/VCC_EXT), Pin 3 = Signal (J2/J7/J9-J13/J15); J8 = GND-VCC_EXT-SDA-SCL
   Begruendung: 3-poliger Stecker: nur der mittlere Pin ist gegen Umdrehen invariant. VCC auf Pin 2 kann nie 3,3 V auf einen MCU-Pin legen und nie die Sensorversorgung ueber unsere Masse kurzschliessen. Fehlerfall bei verkehrtem Stecker: GND/SIG tauschen, der 1-kOhm-Serienwiderstand begrenzt den Strom (ca. 3 mA, pin-sicher). J8 folgt der Qwiic-/STEMMA-Ordnung mit VCC auf Pin 2
36 Serienwiderstand Signale     OK       J2.3->R6(SENSOR_AOUT), Reihe, 1k, Pin 12 (IO0); J7.3->R_LIGHT_S(LIGHT_AOUT), Reihe, 1k, Pin 9 (IO4); J9.3->R_SPARE_AIN(SPARE_AIN), Reihe, 1k, Pin 10 (IO5); J10.3->R_SPARE_IO15(SPARE_IO15), Reihe, 1k, Pin 20 (IO15); J11.3->R_SPARE_IO16(UART_TX), Reihe, 1k, Pin 31 (IO16); J12.3->R_SPARE_IO17(UART_RX), Reihe, 1k, Pin 30 (IO17); J13.3->R_SPARE_IO21(SPARE_IO21), Reihe, 1k, Pin 27 (IO21); J15.3->R_SPARE_IO23(SPARE_IO23), Reihe, 1k, Pin 29 (IO23); J8.3->R_SDA_S(SDA_MCU), Reihe, 1k, Pin 24 (IO18); J8.4->R_SCL_S(SCL_MCU), Reihe, 1k, Pin 25 (IO19) je Signaleingang ein 1-kOhm-Widerstand zwischen Steckerpin und MCU-Pin
   Begruendung: Steckerkabel koennen Fehlerstroeme in die Pins treiben; der Serien-R begrenzt sie. Gilt fuer Sensor/Licht, I2C (SDA/SCL) und alle Reserve-Eingaenge (R6, R_LIGHT_S, R_SDA_S, R_SCL_S, R_SPARE_AIN, R_SPARE_IO15/16/17/21/23); J14 entfaellt
37 Load-Switch-Fail-safe        OK       Q2 S->+3V3 D->VCC_EXT G->EXT_EN, R_GATE an +3V3 OK, IO20 OK, IO20-WPU ja Source +3V3, Drain VCC_EXT, Gate ueber 47 kOhm auf +3V3, IO20 zieht das Gate nach unten, IO20 hat beim Reset WPU
   Begruendung: Load-Switch aus = Fail-safe. Ohne GPIO-Treiber (Reset, Hochohmigkeit, Deep-Sleep) liegt das Gate ueber 47 kOhm auf dem Quellpotential (VGS = 0) und Q2 sperrt. IO20 hat beim Reset einen internen Weak-Pull-up (Espressif ESP32-C6-Datenblatt), der das Gate zusaetzlich hoch haelt -> VCC_EXT ist beim Start aus
38 Sensor-Lastschalter          OK       Q_SENS S->+3V3 D->SENSOR_PWR G->EXT_SENS_EN; R_SENS_GATE 47 kΩ nach +3V3 OK; U1 Pin 6 auf EXT_SENS_EN, IO3 OK; GPIO direkt an VCC: keiner Q_SENS Source +3V3, Drain SENSOR_PWR, Gate EXT_SENS_EN; R_SENS_GATE 47 kΩ nach +3V3 (fail-safe aus); IO3 treibt nur das Gate; kein GPIO direkt an SENSOR_PWR/VCC_EXT
   Begruendung: Review 16.09.2026: die Sensorversorgung direkt aus GPIO3 ist fuer frei anschliessbare Module zu schwach; jetzt treibt IO3 (Pin 6) nur das Gate von Q_SENS (AO3401A, P-Kanal).  Der Pull-up haelt den Schalter bei hochohmigem GPIO aus (P-Kanal: V_GS = 0 sperrt), wie bei Q2
39 Erweiterungs-Pins            OK       Doppelbelegung keine; Zuordnung OK; GPIO8/9 OK kein U1-Pin doppelt, Erweiterungspins wie geplant (ohne J14/IO22), GPIO8/GPIO9 unveraendert auf ihren Strapping-Netzen
   Begruendung: Mengenpruefung der Netzliste gegen Pin-Doppelbelegung. IO22 ist seit 15.09.2026 PUMP2_EN (J16), kein Reserve-Stecker mehr; IO15 waehlt nur die JTAG-Quelle (Default-eFuses = wirkungslos) und ist ueber einen 1-kOhm-Serienwiderstand an J10 gefuehrt; IO16/IO17 bleiben UART0
40 I2C-Pull-ups                 OK       R_SDA_PU 4,7 kΩ an VCC_EXT (Pin 2), R_SCL_PU 4,7 kΩ an VCC_EXT (Pin 2), VCC_EXT geschaltet OK beide 4,7 kOhm, Pull-up-Seite VCC_EXT (nicht +3V3), VCC_EXT geschaltet
   Begruendung: Im ausgeschalteten Zustand zieht der Bus keinen Strom, weil die Pull-ups am geschalteten VCC_EXT haengen (schaltplan §9.5, Revision 15.09.2026: 4,7 kOhm). 4,7 kOhm sind fuer kurze Kabel und die ueblichen 100-kHz/400-kHz-I2C-Module plausibel
41 EN-RC                        OK       10,0 ms (R_EN 10,0 kΩ, C4 1,0 µF)  R_EN·C4 >= 1 ms
   Begruendung: Espressif: R = 10 kΩ und C = 1 µF am EN-Pin; tSTBL nur 50 µs
42 Netzstruktur                 OK       76 Netze, 122 Bauteile, 0 Befunde  jedes Bauteil auf >= 2 Netzen, jedes Netz mit >= 2 Knoten
   Begruendung: Strukturfehler wie Kurzschluss oder fehlender Anschluss (scripts/check_netlist.py)
----------------------------------------------------------------------------------------------------
Simulationen (Annahmen sind unten genannt)
----------------------------------------------------------------------------------------------------
Gate-Treiber @ 20 kHz PWM (R1 1,0 kΩ, R2 47 kΩ, Ciss 630 pF):
   Zeitkonstante tau = 0,62 µs, VGS-Endwert = 3,23 V, Zeit bis 2,5 V = 0,92 µs
   GPIO-Strom: Peak 3,300 mA, Mittel 1,752 mA (Periode 50,0 µs)
Ladezeit 2S (2000 mAh, ICHG 0,90 A):
   CC 1,78 h + CV 1,11 h = 2,89 h (grob, CC/CV-Anteile sind Annahmen)
Dosiervorgang aus der 5-V-Schiene (Pumpe 0,4 A, 2,04 W):
   0,0680 Wh pro 300 ml => 2,00 min; nutzbar 11,84 Wh => 174,1 Dosen pro Ladung
Pumpenanlauf (3,0 A, R_BAT 0,15 Ω):
   Packstrom 2,83 A, VBAT 6,0 V -> 5,58 V, Einbruch 425 mV
5-V-Buck-Rippel (Vin 8,4 V): D 0,607, dI 0,85 A, I_peak 3,43 A
3,3-V-Buck-Rippel (Vin 8,4 V): D 0,393, dI 0,39 A, I_peak 0,58 A
Teilerstroeme bei 8,4 V:
   Waechter (R3a/R3b) 82,4 µA, ADC (R_SENSE_*) 31,3 µA
Standby in mAh/Tag: 242,8 µA = 5,83 mAh/Tag (0,291 % der 2000 mAh-Packkapazitaet)
Tank-LED-Blinken (D5, R_TANK 1,0 kΩ, Vf 2,0 V): 3 x 50 ms alle 5 s (Tastverhaeltnis 3,0 %):
   Dauerbetrieb 1,30 mA, Mittel 0,04 mA -> 0,94 mAh/Tag statt 31,2 mAh/Tag
Licht-ADC (ALS-PT19, R_LIGHT 10 kΩ, ATTEN3 0-3300 mV, 12 Bit):
   0 lx -> 0 Counts (0,000 V); 100 lx -> 186 Counts (0,150 V); 1000 lx -> 1861 Counts (1,500 V); 10000 lx -> 4095 Counts (3,300 V)
Annahmen: Innenwiderstand des 2S-Packs R_BAT = 0,15 Ω (Annahme); Ladezeit: CC-Anteil 80 %, mittlerer CV-Strom 40 % von ICHG (Annahme); nutzbarer Anteil der Packkapazitaet 80 % (Annahme); Buck-Wirkungsgrad beim Anlauf 90 % (Annahme)
----------------------------------------------------------------------------------------------------
Ergebnis: 42 von 42 Pruefungen bestanden, 0 fehlgeschlagen.
```
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

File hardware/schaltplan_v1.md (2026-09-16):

# Schaltplan V1 — Smart Grow Topf

Stand: **16.09.2026, Revision „2S-Umbau"** · **Diese Datei ist die Verbindungsvorgabe für das Layout.**
Alle Bauteilwerte sind aus den Herstellerdatenblättern abgeleitet (Quelle jeweils in der Spalte „Warum").
Maschinenlesbare Fassung derselben Verbindungen: **`schaltplan_v1_netzliste.csv`** (`Netz, Bauteil, Pin, Bemerkung`).

> ⚠️ **Was diese Revision geändert hat (Kurzfassung, Details in §13):**
> 1S-LiPo → **2S-Pack (6,0–8,4 V)**, 1S-Lader → **IP2326** (Boost-Lader aus 5 V USB, 8,4 V / 0,90 A),
> 5-V-**Boost** → 5-V-**Buck**, 3,3-V-**LDO** → 3,3-V-**Buck**, Unterspannungswächter **MAX809 (3,08 V an 1S)**
> → **TPS3839G33 (3,08 V an einem 1:2-Teiler ⇒ 6,16 V Pack)**. Der frühere Klemmzweig war im Bestand
> **unwirksam** (Parallelschaltung statt Serienkette) und ist hier korrigiert (§13.4).

---

## 1. Blöcke
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

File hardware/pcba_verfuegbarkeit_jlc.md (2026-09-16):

# PCBA-Verfügbarkeit bei JLCPCB — Smart Grow Topf V1 (Modul-Variante)

Stand: 15.09.2026 · Methode: JLCPCB-Parts-API (`selectSmtComponentList/v2`, Skill `jlcpcb-parts-check`),
jede Zeile ein echter API-Treffer. Preise = 1-Stück-Staffel in USD. `base` = Basic (keine
Handling-Gebühr) · `expand` = Extended (**+3 USD pro Position**).
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

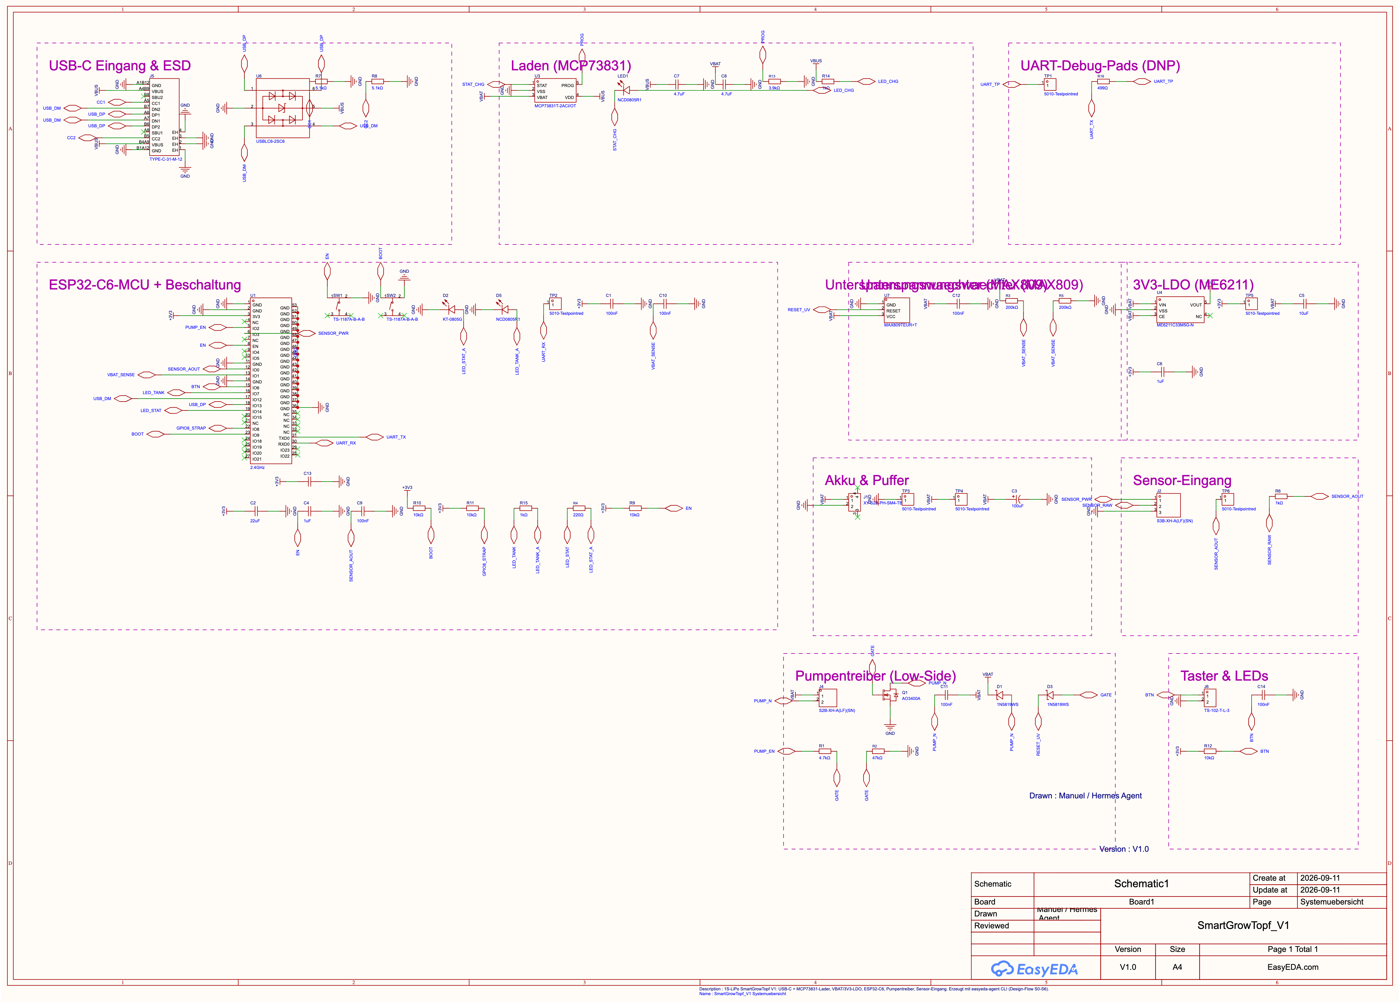
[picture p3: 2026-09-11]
hardware/easyeda/out/SmartGrowTopf_V1_A2_final.png

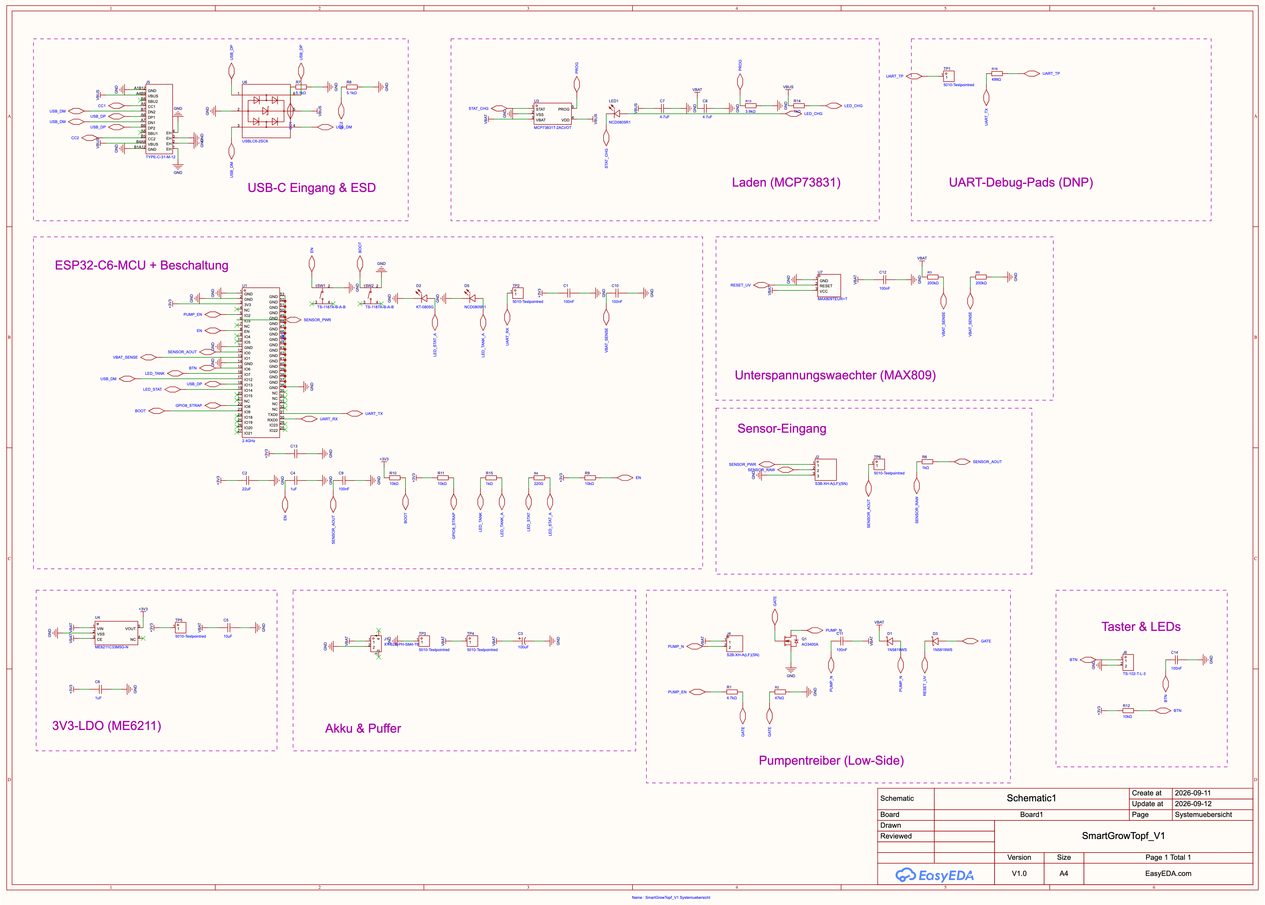
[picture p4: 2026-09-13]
hardware/easyeda/out/vor_neubau_2026-09-13.png

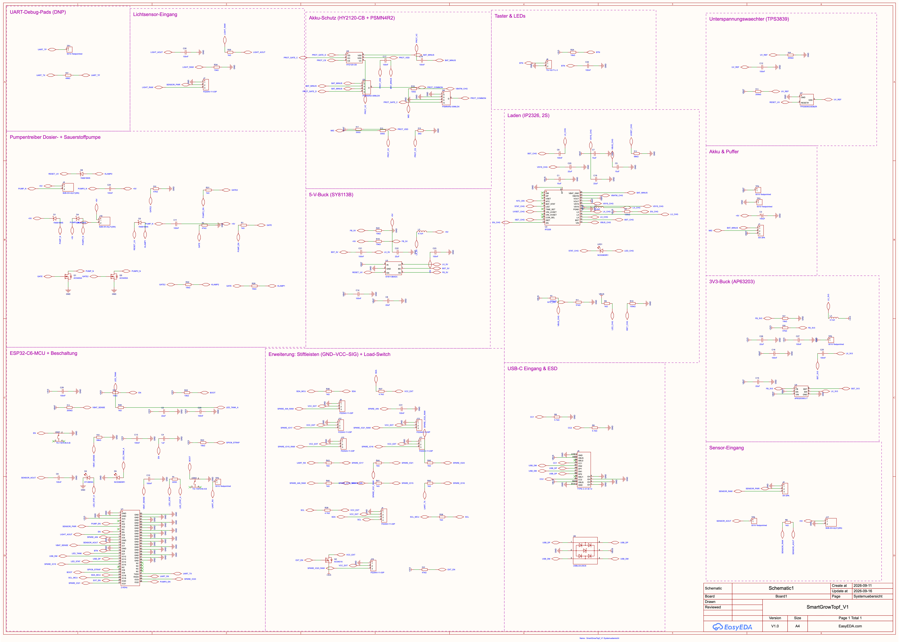
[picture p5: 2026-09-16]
hardware/easyeda/out/schaltplan_2026-09-16_2s_schutz.png

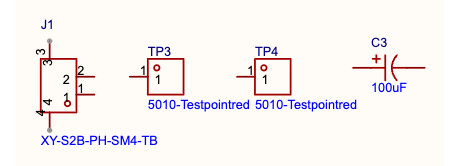
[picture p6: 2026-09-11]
hardware/easyeda/s4/akku.png

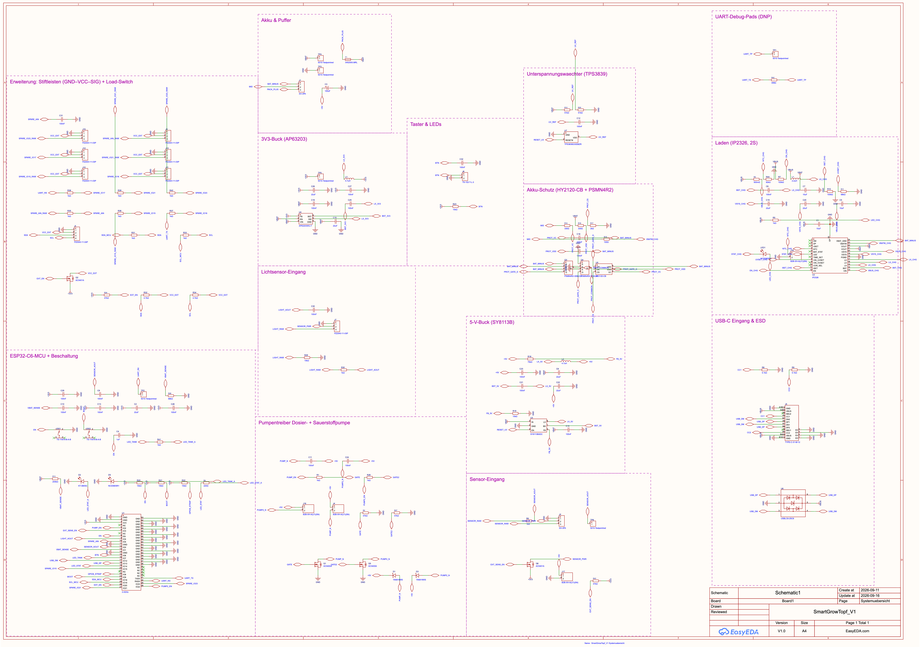
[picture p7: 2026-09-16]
hardware/easyeda/out/schaltplan_2026-09-16_2s_review.png

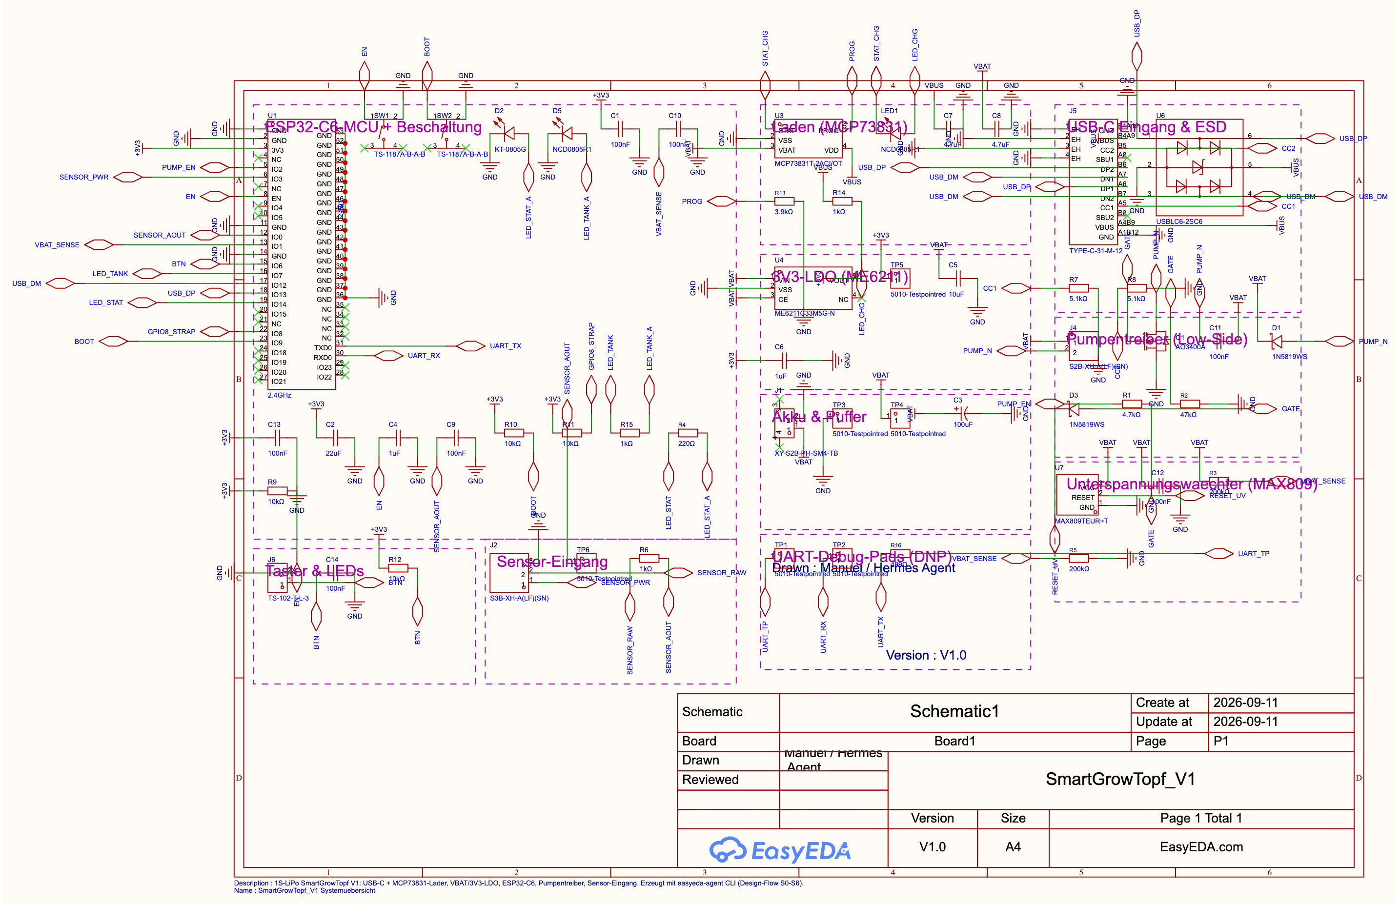
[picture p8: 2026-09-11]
hardware/easyeda/out/SmartGrowTopf_V1_Systemuebersicht.png

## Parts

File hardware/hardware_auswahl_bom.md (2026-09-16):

# Hardware-Auswahl & BOM — Smart Grow Topf (V1)

Stand: 11.09.2026 · Konzept: **Top-Drip mit Rücklauf** (Pumpe fördert auf einen Verteilerring auf der Erdoberfläche), eigene PCB, Akku, peristaltische Pumpe (Schlauch quetschen), kapazitiver Sensor (analog), Telegram-Alarm.
➡️ **Finale Auswahl mit geprüften Preisen: [`bom_entscheidung.md`](bom_entscheidung.md)** · Preisrecherchen: `../research/bom-check/` · Verbindliche Maße: `../docs/02_architektur-und-geometrie.md`
Dieses Dokument ist die Recherche-/Ideenebene (inkl. Alternativen und Ausschlussgründen) und wird nicht mehr als Bestellgrundlage verwendet.

> ⚠️ **Historisch, Stand 10.09.2026.** Genannt werden hier noch der **XIAO ESP32-C6** (verworfen,
> jetzt ESP32-C6-MINI-1), die **Adafruit-Pumpe** und der **Gate-Widerstand 220 Ω** (beide verworfen).
> Verbindlich sind ausschließlich `bom_entscheidung.md` und `schaltplan_v1.md`.
>
> ⚠️ **Versorgungskette (Stand 16.09.2026, Revision „2S-Umbau"):** **2S-Pack 6,0–8,4 V**
> (BMS mit Balancing Pflicht) → Lader **IP2326** (8,4 V / 0,90 A aus 5 V USB) → **Buck SY8113B**
> (U_BUCK5) → **+5 V (5,10 V)** für beide Pumpen und J17 · **Buck AP63203** (U_BUCK3) → **+3,3 V**
> (3,31 V) für die Logik · Wächter **TPS3839G33**. **Kein LDO, kein Boost.** Alle Angaben unten zu
> **1S-Zelle, MCP73831, ME6211, MT3608 und „Pumpe direkt an der Zelle"** sind damit überholt —
> maßgeblich ist `schaltplan_v1.md` (§1–§6).

---

## 1. Entscheidende Eckpunkte (vom User)

| Punkt | Vorgabe |
|---|---|
| Topf | **Ø 140 mm**, Erdbehälter **150 mm hoch**; darunter Wassertank **1,0 L** (Gesamthöhe 278 mm) |
| MCU | **XIAO ESP32-C6 als Modul** auf eigener PCB (festgelegt 11.09.2026) |
| Pumpe | **Peristaltisch** (Schlauch quetschen) — Medium kommt nie mit der Pumpenmechanik in Kontakt; **klein + günstig**, sitzt in der Seitenwulst |
| Energie | **Akku** (nicht Netz) — Kapazität selbst zu ermitteln |
| Elektronik | **eigene PCB**, in der Seitenwulst über dem Wasserstand |
| Sensor | kapazitiv v1.2 (LDO), **analoger Ausgang**, von oben eingesteckt, Messebene 75 mm |
| Leer-Meldung | kurz ins WLAN → **Telegram** (final) |
| Nährlösung | **nur Wasser** im Tank, keine Düngerdosierung |

---

## 2. Komponenten-Empfehlung

### 2.1 Peristaltische Pumpe (klein + günstig + akkutauglich)

**Empfehlung (Stand 14.09.2026): CONQUERALL DC-5-V-Mikro-Peristaltikpumpe — 11,99 €**
- **≤ 150 ml/min**, Nennspannung **DC 5 V**, Leerlaufstrom 0,4 A, **Anlaufstrom 3 A (bei 5 V)**
- Silikonschlauch **3 × 5 mm** (passt zum bestellten Schlauch), Bauhöhe 42 mm, Ansaugbereich 0,5 m
- Schlauch quetschen, selbstansaugend, Richtung per Umpolung umkehrbar
- Amazon: https://www.amazon.de/dp/B0DHVMZ27Y · 2er-Pack `B0DJ78W43W` 16,61 €
- ⚠️ Ø nicht dokumentiert; sie läuft seit dem 2S-Umbau an der **geregelten 5-V-Schiene (5,10 V)**,
  also an ihrer Nennspannung; Anlaufstrom 3 A
  → **PWM-Softstart empfohlen** und Messauftrag: `bom_entscheidung.md` §4c/§7, `docs/11_review-2s-umbau.md` §4.4

**Geprüft und verworfen (14.09.2026):**

| Produkt | Preis | Warum nicht |
|---|---|---|
| „6V-Mini-Peristaltik" `B0HC8WF98P` / `B0H7R9XYJ5` | 5,99 / 6,69 € | Produkttext wörtlich: **„Spannungen unter 6 V betreiben den Motor nicht"** → an 1S unbrauchbar |
| Funduino „0–90 ml/min, 3–12 V" `B0DT1JCFNV` | 11,39 € | Titel nennt 3–12 V, Produktdetails **keine Spannung/kein Strom** → Akku-Auslegung nicht belegbar |
| Whadda WPM447 `B09L4SR2MY` | 14,18 € | 39 ml/min bei 5 W → fünffache Energie pro Liter |
| 12-V-Klasse (G528/G928, Kamoer NKP) | ab 16 € | bräuchte einen Boost, den die Platine nicht hat (die 5-V-Schiene ist ein **Buck**) |
| Schrittmotor-Mikropumpen 3–5 V `B0GGRLZ23B` | 18,88 € | 0,5 ml/min → 10 h für eine Dosis |
| „Peristaltikpumpe 3,7/6/12 V … **Membran** Luftpumpe" | 18–19 € | sind **keine** Peristaltikpumpen (Titel-Fehler), Medium hätte Kontakt |

> **Warum 3–6V statt 12V:** Für Akkubetrieb ist eine 3–6V-Pumpe über eine geregelte 5-V-Schiene einfacher und effizienter. 12V bräuchte einen Step-Up und mehr Zellen. Bei einem kleinen Topf ist der Durchfluss eh klein — die Funduino (0–90 ml/min) reicht. *(Stand 14.09.2026: die 5-V-Schiene entsteht aus dem 2S-Pack per **Buck** — die frühere Begründung „direkt an der Zelle" gilt nicht mehr.)*

> **Durchfluss-Timing (kleiner Topf ~3–6 L):** 0,3–0,6 L pro Gießvorgang. Bei 60 ml/min → **5–10 min** Dauerlauf; kann in 2–3 Portionen mit Pausen erfolgen. Genau kalibrieren (30 s in Messbecher pumpen → nachmessen), Mini-Pumpen streuen ±30 %.

### 2.2 ESP32-Board

**Empfehlung: Seeed XIAO ESP32-C6** (~6 $) — WiFi 6, BLE, **15 µA Deep-Sleep**, alle ADC-Kanäle auf ADC1 (kein ADC2-Fallstrick), LiPo-Lader onboard (passt zum Akku), 21×17,8 mm klein.
- https://www.seeedstudio.com/Seeed-Studio-XIAO-ESP32C6-p-5884.html

**Alternative (günstiger):** XIAO ESP32-C3 (~5 $) — reicht (1 Sensor = 1 ADC1-Pin), aber 44 µA Sleep und A3 nur 3 zuverlässige ADC-Pins.

### 2.3 Pumpen-Ansteuerung (eigene PCB)

- **N-Kanal-Logic-Level-MOSFET** (z. B. IRLZ44N oder AO3400) als Low-Side-Schalter:
  - GPIO → 220 Ω → Gate
  - Gate → 10 kΩ → GND (Pull-down: Pumpe sicher AUS beim Boot/Reset)
  - Drain → Pumpe(−), Pumpe(+) → Versorgung; Source → GND
  - **Freilaufdiode** antiparallel zur Pumpe: 1N5819 (Schottky) schützt gegen Induktionsspitzen
- **Fertiges Dual-MOSFET-Modul** (5–36V, 15A) als no-solder-Alternative: 8 Stk **6,49 €** → https://www.amazon.de/dp/B0DG8B58PM
- **Relais:** möglich, aber hörbar + kein PWM — MOSFET ist für Akku besser (kein Spulendauerstrom).

### 2.4 Kapazitiver Bodenfeuchte-Sensor (analog)

- Typ **Capacitive Soil Moisture v1.2 / v2.0** (tropfenförmige grüne Platine, analog 0–3V). Betrieb bei 3,3V ok, Ausgang direkt an ADC.
- **Sensor-VCC per GPIO schalten** (nur während Messung an) — verhindert Korrosions-/Galvanik-Drift und spart Strom.
- Keine Library — `analogReadMilliVolts()` + Median (12 Messungen) + Moving Average.
- **Kalibrierung** in der eigenen Erde: trocken = 0 %, gesättigt = 100 %, als linearer Map. Schwellwert **~35 %** (pumpen) / **~50 %** (Hysterese, Recovery).

### 2.5 Akkupack

| Komponente | Wert | Begründung |
|---|---|---|
| Pack | ~~LiPo 3,7 V, 1000–2000 mAh~~ **→ 2S-Pack 6,0–8,4 V (1500–2500 mAh), BMS mit Balancing** | Pumpe läuft nur minutenweise pro Zyklus; Reihenzellen brauchen Balancing |
| Lade-IC | ~~**MCP73831**~~ **→ IP2326** (2S-Boost-Lader, 8,4 V / 0,90 A) | ~0,62 $, LCSC `C2832094` |
| Versorgung | ~~Pumpe direkt von der Zelle~~ **→ Buck SY8113B (+5 V) und Buck AP63203 (+3,3 V)** | Sensor+ESP 3,3 V, beide Pumpen 5 V |
| Tiefentladeschutz | Zellen-Schutz-PCB / BMS | LiPo-Pack mit Schutz wählen |

**Strombudget-Berechnung (Basis):**
- **Ruhe:** ESP32 Deep-Sleep **15 µA** (oder Light-Sleep ~3,1 mA mit WiFi) + Sensor nur bei Messung an.
- **Messung:** kurz (ms), ~5–10 mA währenddessen.
- **Pumpe:** z. B. 250 mA bei 6 V, aber nur **5–10 min pro Gießvorgang**, Gießen selten (alle 1–3 Tage).
- **Mess-Takt:** alle 5–10 min messen (0,1 s Messung) → vernachlässigbar.
- **Telegram:** nur bei Ereignis (Tank leer / nachgefüllt), kurz WiFi an.

**Abschätzung:** 2000-mAh-LiPo ≈ 7,4 Wh.
- Ruhe-Last (Deep-Sleep 15 µA) über 30 Tage ≈ 0,011 Wh — vernachlässigbar.
- 1 Gießvorgang: 8 min × 250 mA @ 3,7V ≈ 0,12 Wh; bei ~1×/Tag+Toleranz → **eine 1000–1500-mAh-Zelle hält problemlos 2–4 Wochen** ohne Nachladen.
- **Empfehlung: 1× 18650 (2500–3000 mAh) oder LiPo 2000 mAh** mit Schutz-PCB — großzügig dimensioniert.

---

### 2.6 Sauerstoffpumpe (optional, 5 V) — gewählt 15.09.2026

**Mini USB Aquarium Luftpumpe mit Luftstein — Amazon `B0FXB5BMTT`, 8,48 €** (3,9 ★)
5 V USB, ~1 W (0,20 A), < 35 dB, für 10–40 L, dauerbetriebsfähig; **Lieferumfang: Pumpe,
1,15 m Silikonschlauch, Luftsprudler**. Anschluss über **JST-XH 2P (J16)**, Steuerung **IO22**.
Alternativen: `B093GPMT1Z` (9,99 €, 210 L/h) · `B0B82JX6Z4` (7,29 €, regelbar).
Vollständige Tabelle, Strom-/Laufzeitrechnung und Anbindung: `bom_entscheidung.md` §8.

## 3. Gesamtkosten (Kern-Hardware, Schätzung)

| Komponente | Preis |
|---|---|
| XIAO ESP32-C6 | ~6 $ |
| Peristaltische Pumpe (CONQUERALL 5 V) | 11,99 € |
| MOSFET (IRLZ44N 10er) / Fertigmodul | ~7 € |
| Kapazitiver Sensor v2.0 | ~3–5 € |
| Freilaufdiode 1N5819 | <1 € |
| LiPo/18650 + Schutz + Lade-IC | ~8–12 € |
| **Summe (ohne PCB/Optik)** | **~35–45 €** |

---

## 4. Noch offen

- ✅ **Entschieden 11.09.2026:** MCU = **XIAO ESP32-C6 als Modul** (Castellated Pads) auf der eigenen PCB; USB-C-Buchse bleibt durch Gehäuseöffnung erreichbar, onboard-LiPo-Lader wird mitgenutzt.
- ✅ Tankvolumen / Topf-Innengeometrie → berechnet, siehe `../docs/02_architektur-und-geometrie.md` (1,0 L, Gesamthöhe 278 mm).
- ✅ Montageorte: Elektronik + Pumpe in der Seitenwulst (über dem Wasserstand), Sensor von oben, Druckschlauch auf Verteilerring.
- ✅ Telegram final (ntfy.sh verworfen).
- ⏳ Preise/Verfügbarkeit aller Teile → `../research/bom-check/` (läuft)
- ⏳ Zellenwahl final (Bautiefe ≤ 30 mm in der Wulst).

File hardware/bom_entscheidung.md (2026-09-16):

# BOM-Entscheidung V1 — Smart Grow Topf

Stand: 11.09.2026, nachrecherchiert 12.09.2026 · Preise direkt auf der Produktseite geprüft (Spalte „Prüfung“)
Grundlage: `../research/bom-check/01…04` · **Nachrecherche 12.09.2026: `../research/bom-check/09_eu-quellen-konsolidiert.md`** (Pumpe/Sensor/Schlauch, EU-Quellen) · Geometrie: `../docs/02_architektur-und-geometrie.md`

---

## 1. Entscheidung (final)

| # | Bauteil | Wahl | Preis | Bezug / Link | Prüfung |
|---|---|---|---|---|---|
| 1 | **MCU** | **ESP32-C6-MINI-1** (nacktes Modul auf eigener PCB) | **≈ 3,60 €** (3,8871 $) | JLCPCB `C5736265` | ✅ API + Espressif-Datasheet |
| 1b | MCU-Alternative | ESP32-C6-MINI-1**U** (IPEX, externe Antenne) | ≈ 3,99 € (4,3051 $) | JLCPCB `C20627095` | ✅ API (1.352 lagernd) |
| 1c | **2S-Lader** ⭐ | **IP2326**, 2S-Boost-Lader aus 5 V USB, 8,4 V / 0,90 A | ≈ 0,62 $ | JLCPCB `C2832094` | ✅ API (18.074 lagernd) + Datenblatt V1.11 (VSET offen = 8,4 V; ICHG = 90000/R_ISET; kein Power-Path). ⚠️ Variante **IP2326_8V8 = 8,8 V** nicht verwenden |
| 1d | **3,3-V-Buck** ⭐ | **AP63203WU-7**, 2 A, 3,8–32 V, **Iq 22 µA** (ersetzt den LDO) | ≈ 1,18 $ | JLCPCB `C780769` | ✅ API (25.645) + Datenblatt DS41326. Der ME6211 entfällt: V_IN,max 6,0 V und 0,26 W Verlust bei 8,4 V → 3,3 V |
| 1e | **USB-C + Schutz** | Buchse 16-pol `C165948` + USBLC6-2SC6 `C7519` + 2 × 5,1 kΩ `C27834` | ≈ 0,40 € | JLCPCB | ✅ API |
| 1f | **Unterspannungswächter (2S)** ⭐ | **TPS3839G33DBZR**, 3,08 V, **Iq 150 nA**, Push-Pull | ≈ 0,45 $ | JLCPCB `C485802` | ✅ API (3.502) + Datenblatt (V_IT 3,003–3,126 V, Hysterese 31 mV). Am 1:2-Teiler ⇒ **6,16 V Pack**. Der MAX809 scheidet aus: V_DD,max 5,5 V |
| 2 | **Pumpe** | **CONQUERALL DC-5-V-Mikro-Peristaltikpumpe** (Amazon `B0DHVMZ27Y`) — Nennspannung **DC 5 V**, Leerlaufstrom 0,4 A, **Anlaufstrom 3 A (bei 5 V)**, Fördermenge **≤ 150 ml/min**, Silikonschlauch **3 × 5 mm**, Bauhöhe **42 mm**, Ansaugbereich 0,5 m, umpolbar | **11,99 €** (2er-Pack `B0DJ78W43W` **16,61 €**) | https://www.amazon.de/dp/B0DHVMZ27Y (Verkäufer EASFFY, auf Lager, 4,2★/11) | ✅ Preis + Specs 14.09.2026 (Amazon) · ⚠️ **Ø nicht dokumentiert** → vor Einbau messen (Wulst ist auf Ø 32 gerechnet) · ⚠️ Betrieb an 1S (3,0–4,2 V) liegt **unter** der Nennspannung → Förderrate + Anlauf **messen** · ⚠️ **Anlaufstrom** → siehe §4c: PWM-Softstart ist Pflicht |
| 2b | ~~OEM-Peristaltik ABC-12527~~ | **abgelöst (14.09.2026)** — war fachlich passend (3,7–6 V, ab 3 V dokumentiert, Ø32 × 44 mm, ~250 ml/min), aber **31,94 €** inkl. 24,20 € Versand aus Litauen (anodas.lt) | – | anodas.lt | Historie: `../research/bom-check/06_pumpe-eu-quellen.md` |
| 3 | **Sensor** | Kapazitiv **v1.2**, analog — **AZ-Delivery ausverkauft (12.09.)**, Ersatz: **ARCELI 6er-Pack V1.2 kapazitiv** (1,25 €/St.) | **7,49 €** (6 St.) | Amazon `B0FPRBY7LW` · AZ (falls wieder lieferbar) https://www.az-delivery.de/products/bodenfeuchte-sensor-modul-v1-2 | ✅ selbst 12.09. (7,49 €, ab Lager, Gratislieferung 16.09.) · ⚠️ Elektrodenlänge bleibt unbelegt |
| 4 | **Akku (2S)** ⭐ | **Keeppower 2S1P 2×18500 2000 mAh** (18,5 × 103 mm, 70 g, ~14,8 Wh); Alternative **2×18650 3400 mAh** (18,7 × 134 mm, 100 g, ~25 Wh) | **10,90 €** / **14,90 €** | akkuteile.de (beide auf Lager, 16.09.2026) | ✅ Preise + Lager live geprüft (`../research/bom-check/10_2s-akku-quellen.md`). Schutzplatine (Seiko) dokumentiert, **Balancing nicht** → drei Wege in `hardware/schaltplan_v1.md` §6.3. Betrieb 6,0–8,4 V, Wächter-Abschaltung bei 6,16 V |
| 5 | **MOSFET** | **AO3400A** (SOT-23), 10 St | **1,67 €** | Reichelt, ab Lager — https://www.reichelt.de/de/de/shop/produkt/mosfet_n-ch_30v_5_7a_0_018r_sot-23-166490 | ✅ selbst (0,167 €/St ab 10) |
| 6 | **Freilaufdiode** | 1N5819 (DO-41), 10 St | ~1,00 € | Reichelt | ⚠️ Subagent, nicht selbst geprüft |
| 7 | **Sensor-Stecker** | JST-XH 2,54 3-pol Buchse, 10 St | 3,00 € | Funduinoshop | ⚠️ Subagent |
| 8 | **Schlauch** | Silikon **3 mm ID × 5 mm OD, lebensmittelecht, 3 m** | **6,99 €** | Amazon `B0CMQJDJ2H` (Gratislieferung 16.09.) | ✅ selbst 12.09. |
| | **Zwischensumme** (Position 1–7) | | **≈ 38.64 €** | | |
| 9 | **Passive** (Werte jetzt aus dem Schaltplan): R 1 kΩ/3,9 kΩ/4,7 kΩ/10 kΩ/47 kΩ/200 kΩ/5,1 kΩ · C 100 nF/1 µF/4,7 µF/10 µF/22 µF/100 µF · 2 Taster | ~5 € | JLCPCB (PCBA, Basic-Teile) | ✅ LCSC-Codes in `pcba_bom_jlc.csv`; ⚠️ Hinweis: „220 Ω" und „Stiftleisten" aus der alten Zeile sind **entfallen** (Gate-Widerstand jetzt 4,7 kΩ, kein XIAO-Sockel mehr) |
| 10 | Ansaugfilter/-gewicht | optional | Badshop/Aquaristik, Preis offen | ❌ |
| | **Gesamt (realistisch)** | | **≈ 47–49 €** | inkl. Schlauch (3–5 €) und Passiven (~5 €) | |
| | **+ JLCPCB-Kosten (nicht in dieser BOM)** | | **≈ 28 € Handling** | 10 Extended-Positionen à 3 $ + Platinenfertigung (noch kein Angebot eingeholt) | |

**Was die Pumpenwahl geändert hat (14.09.2026):** Die Pumpe ist jetzt die **CONQUERALL DC 5 V**
(11,99 €, Amazon, sofort lieferbar) — statt 31,94 € für die OEM-Pumpe aus Litauen. Das spart
**19,95 €**, verschiebt aber ein Risiko: die OEM war **ab 3 V dokumentiert**, die CONQUERALL ist mit
**5 V Nennspannung** spezifiziert und läuft an der 1S-Zelle (3,0–4,2 V) *unterhalb* ihrer Nennspannung.
Förderrate bei 3,7 V und Anlaufverhalten sind damit **nicht belegt → messen** (§7). Der Anlaufstrom
(3 A bei 5 V) ist der zweite neue Punkt und in §4c gegen die Schaltung geprüft.

---

## 2. Warum diese Pumpe — die Kennzahl ist Wh pro Liter

Für ein Akkugerät entscheidet nicht der Preis allein, sondern die Energie pro gefördertem Liter.
Alle Werte aus Produktseiten/Datenblättern, Umrechnung in Wh/L aus Leistung und Förderrate:

| Pumpe | Preis | Leistung | Förderrate | **Wh/L** | Quelle |
|---|---|---|---|---|---|
| **CONQUERALL DC 5 V** @5 V (Nenn) | **11,99 €** | 2,0 W (5 V × 0,4 A) | ≤ 150 ml/min | **0,22** | Amazon `B0DHVMZ27Y` (Datenblattangaben des Händlers) |
| CONQUERALL DC 5 V @3,7 V (1S-Betrieb) | 11,99 € | ~1,5 W* | ~111 ml/min* | **0,22** | *lineare Skalierung — **Annahme, nicht belegt** |
| ~~OEM ABC-12527~~ @3,7 V (abgelöst) | 7,74 € + 24,20 € Versand | 1,67 W | ~154 ml/min* | 0,18 | anodas.lt (Spannung + Strom dokumentiert) |
| Adafruit 3910 @5 V | 24,50 € | 2,50 W | 100 ml/min | 0,42 | adafruit.com/product/3910 |
| Whadda WPM447 @6 V | 12,90 € | 5,00 W | 39 ml/min | 2,14 | whadda.com + electrokit.se |

\* Die Förderrate der CONQUERALL ist nur als **Obergrenze bei Nennspannung** angegeben und die
Spannungsskalierung ist meine Annahme → **vor dem Einbau messen** (§7). Bei 3,7 V ergibt sich damit
eine Laufzeit von ~2,7 min für 300 ml.

**Was an der CONQUERALL gemessen wurde (14.09.2026, Amazon-Produktdaten):**
> „Nennspannung: DC 5V · Leerlaufstrom: 0,4 A · Ansaugbereich: 0,5 m · Anlaufstrom: 3 A ·
> Fördermenge: ≤150 ml/min · Pumpe Gesamthöhe: 42 mm · Schlauchdurchmesser: 3 × 5 mm"

**Warum diese und nicht die anderen Amazon-Typen:** Die billigen „6-V-Mini-Peristaltikpumpen"
(5,99–6,69 €, z. B. `B0HC8WF98P`, `B0H7R9XYJ5`) schreiben im Produkttext ausdrücklich
**„Spannungen unter 6 V betreiben den Motor nicht"** → an der 1S-Zelle unbrauchbar. Die
12-V-Klasse (G528/G928/Kamoer NKP) bräuchte einen Boost, den die Platine bewusst nicht hat.
Schrittmotor-Mikropumpen (3–5 V) fördern nur 0,5 ml/min, die G10-Klasse 1 ml/min → beide
viel zu langsam. „Peristaltikpumpe 3,7/6/12 V … Membran Luftpumpe" sind **keine** Peristaltikpumpen
(Titel-Fehler der Händler) → kommen für „Medium berührt die Mechanik nicht" nicht infrage.

Verifizierter Spec-Block der OEM-Pumpe (Wortlaut der Produktseite):
> „Rated voltage: 3.7V to 6V · Current: 3V – 400mA, 6V – 540mA · Engine: DC with pinion ·
> Number of satellites: 3 · Productivity: 1L – 4 min · Dimensions: Diameter: 32 mm. Height: 44 mm ·
> Mounting holes diameter: 2.5 mm · Mounting hole layout 44mm · Silicone tube: inner 3 mm / outer 5 mm"

**Einschränkung:** kein deutscher Shop — EU-Versand aus Litauen (Vilnius/Kaunas lagernd), Versand
nach DE laut Seite „auf Anfrage". Das ist der Preis für 17 € Ersparnis; Lieferzeit und Versandkosten
vor der Bestellung klären.

---

## 3. Betriebsspannung — ~~der frühere offene Punkt ist geschlossen~~ **revidiert am 15.09.2026**

> **⚠️ NEU (15.09.2026): Es gibt jetzt einen Boost.** Auf Wunsch des Nutzers sollen **beide** Pumpen
> (Dosier- **und** Sauerstoffpumpe) **5 V** bekommen. Damit ist der Direktbetrieb an der 1S-Zelle
> gestrichen: **U8 MT3608** erzeugt eine geregelte **+5-V-Schiene (5,10 V)** aus VBAT, und **beide**
> Pumpen hängen über je einen AO3400A (Q1/Q3) daran. Auslegung, Rechnungen und die zwei harten
> Konsequenzen (**PWM-Softstart Pflicht**, **O2-Pumpe nicht im Dauerbetrieb**) stehen in
> `hardware/schaltplan_v1.md` **§10**. Die Absätze unten bleiben als Begründung stehen, warum es
> vorher keinen Wandler gab.

**Entscheidung bis 14.09.2026: 1S-Akku (3,7 V) direkt an der Pumpe, kein Boost, kein Buck.**

Der Grund ist der Pumpentyp. Die frühere Planung stand auf der Prämisse, dass die Pumpe
5–6 V braucht (Adafruit 3910, Herstellerangabe „Motor voltage: 5 to 6 VDC") und der Direktbetrieb an
einer 1S-Zelle damit undokumentiert war — zusätzlich liefert der XIAO im Akkubetrieb **keine 5 V**
(Seeed-Wiki, wörtlich: „When using battery power, no voltage will be present on the 5V pin"),
es hätte also zwingend einen Wandler gebraucht.

**Der damalige Fix war die OEM-Pumpe (ab 3 V dokumentiert). Mit der CONQUERALL ist diese Sicherheit
wieder weg** — sie ist mit **Nennspannung DC 5 V** spezifiziert (Leerlaufstrom 0,4 A), die 1S-Zelle
liefert 3,0–4,2 V. Die Pumpe läuft damit **unterhalb ihrer Nennspannung**, und daraus folgt:

- **Förderrate:** linear geschätzt ~111 ml/min bei 3,7 V statt 150 ml/min → für 300 ml noch
  2,7 min, für die größte Dosis (350 ml) unter 4 min (§4). **Annahme, nicht belegt → messen.**
- **Anlauf:** bei Unterspannung ist das Losbrechmoment nicht garantiert. Der Anlaufstrom *sinkt*
  mit der Spannung (2,5 A bei 4,2 V … 1,8 A bei 3,0 V) — das entlastet Zelle und PCM, sagt aber
  nichts darüber, ob der Motor dreht. **Messen: 3,0 / 3,7 / 4,2 V, je 30 s in den Messbecher (§7).**
- **Boost bleibt verworfen:** ein Step-Up auf 5 V kostet Wirkungsgrad und Platinenfläche. Er ist die
  **Rückfallebene**, falls die Messung zeigt, dass die Pumpe an der Zelle nicht sicher anläuft —
  nicht die Voreinstellung.

**Zum Vergleich — warum es mit der abgelösten OEM-Pumpe unkritisch war:** sie war **ab 3 V
dokumentiert** (3 V – 400 mA) und für 3,7–6 V ausgelegt, lief also **innerhalb** ihres
Datenblattbereichs über den ganzen Entladezyklus — genau dafür war sie ausgewählt worden
(`../research/bom-check/06_pumpe-eu-quellen.md`). Dieser Vorteil ist mit dem Preis der
CONQUERALL (11,99 € statt 31,94 €) bezahlt.

**Das 2S-Konzept (2 Zellen + Step-Down) wurde am 16.09.2026 auf Wunsch des Nutzers umgesetzt** —
die damalige Gegenrede ist damit überholt und bleibt nur als Historie unten stehen. Was sich geändert hat
und warum: `hardware/schaltplan_v1.md` **§13** + `docs/11_review-2s-umbau.md`.
Kernpunkte: der Lader (IP2326) bringt ein eigenes 2S-Balancing mit, der Buck deckt den 3-A-Pumpenanlauf
(der 1S-Boost konnte das nicht), und die nutzbare Zellspanne reicht jetzt bis 6,16 V statt bis ~3,5 V.

**Die frühere Gegenrede (Stand 15.09.2026, hier als Historie):**
- **Wirkungsgrad bringt nichts:** Buck aus 2S (η 0,90) gegen Boost aus 1S (η 0,88) — Laufzeit
  praktisch identisch (32 vs. 31 Tage gerechnet). Und solange die Pumpe direkt an 1S läuft,
  entfällt die Wandlung komplett, das ist besser als jede Wandlung.
- **Kosten:** 2S braucht einen **eigenen Lader plus Balancer**, weil der Onboard-Lader des XIAO für
  eine Zelle (3,7 V / 4,2 V Ladeschluss) ausgelegt ist. Das sind zusätzliche Bauteile und
  Platinenfläche — bei einem Konzept, dessen Ziel „günstig" ist, der falsche Hebel.
- **Kapazität wird nicht gebraucht:** siehe §4 — die 1S-Zelle reicht für ~65 Dosiervorgänge.
- **Sicherheit:** Reihenschaltung ohne sauberes Balancing ist in einem feuchten Gehäuse ein
  echtes Risiko, nicht nur ein Schönheitsfehler.

## 3b. Reicht die Pumpe für Hub und Volumen? — nachgerechnet (14.09.2026)

Gegen die echten Projektwerte (`../docs/02_architektur-und-geometrie.md`): Hub Pumpenmitte
(y ≈ 114) bis Verteilerring auf der Substratoberfläche (y ≈ 260) = **~200 mm**, Saughöhe bis
Tankboden (y ≈ 8) = **~106 mm**, Dosis **150–350 ml** (gerechnet mit 300 ml), Tank 1,0 L.

| Prüfung | Rechnung | Ergebnis |
|---|---|---|
| **Förderhöhe** | 200 mm Wassersäule = ρ·g·h = **0,0196 bar** | gegen typ. 0,5–1 bar Pumpendruck → **20–40× Reserve** |
| **Leitungsverlust** | Hagen-Poiseuille, 3 mm ID, ~450 mm Weg, 150 ml/min | **0,0057 bar** → Gesamt-Gegendruck **0,025 bar** |
| **Saughöhe** | 106 mm gegen Datenblatt „Ansaugbereich 0,5 m" | **4,7× Reserve** ✅ |
| **Volumen/Zeit** | 300 ml bei 111 ml/min (3,7 V) | **2,7 min** (4,2 V: 2,4 min · 3,0 V: 3,3 min); größte Dosis 350 ml < 4 min ✅ |
| **Laufzeit** | 0,068 Wh je 300-ml-Dosis, 4,44 Wh nutzbar aus 1500 mAh | **~65 Dosen pro Ladung** ≈ 2,2 Monate bei 1×/Tag |
| **Tankfüllung** | 1000 ml / 300 ml | **3,3 Dosiervorgänge** → Tank alle 3–6 Tage nachfüllen (Blüte: 1–2 Tage/Gabe) |

**Fazit:** **Hub und Volumen sind kein Ausschlusskriterium** — die Förderhöhe ist bei Peristaltik
Trivialphysik (0,02 bar gegen ≥0,5 bar Pumpendruck). Die offenen Punkte liegen ausschließlich in
der **elektrischen Anlaufbarkeit** bei Unterspannung (§4c) und in der **Dosiergenauigkeit**:
Mini-Pumpen streuen laut eigener BOM-Notiz ±30 %, d. h. 300 ml können 210–390 ml werden →
Laufzeit einmal kalibrieren (30 s in den Messbecher), nicht blind auf ml/min vertrauen.

Wenn 2S später doch gewünscht wird (z. B. für mehr Reserven), ist der Weg dokumentiert: 2S-Lader
mit Balancer + Buck auf 5 V, und der Onboard-Lader des XIAO wird nicht mehr genutzt.

---

## 4. Akku und Laufzeit

- **EFASO 503759**: ~**59 × 37 × 5 mm** (Typcode; Maße am Listing **nicht** bestätigt → vor Bestellung
  Specblock prüfen), mit **PCM** (Über-/Tiefentladung, Kurzschluss) und **JST PH2.0-2P**.
- **Laden:** eigener **MCP73831T-2** auf der Platine, USB-C-Buchse direkt daneben. Die **-2-Variante**
  ist die 4,20-V-Ausführung (aus dem Datenblatt geprüft); die Familie hat auch 4,35/4,40/4,50 V,
  die unsere Zelle zerstören würden. Ladestrom über einen Widerstand programmierbar (15–500 mA),
  sinnvoll ~250 mA für die 1500-mAh-Zelle. Lade-LED am Tri-State-Statusausgang.
  Der XIAO ist nicht mehr im Design — sein Onboard-Lader (SGM40567-4.2) wäre bei JLC ohnehin nicht beschaffbar. (Beim späteren Aufbau mit nacktem ESP32-Modul muss ein eigener 1S-Lader
  vorgesehen werden, z. B. MCP73831.)
- **Laufzeit neu gerechnet (14.09.2026, CONQUERALL @3,7 V: ~1,5 W, ~111 ml/min):** ein Dosiervorgang
  von 300 ml braucht **~2,7 min** und **0,068 Wh**. Aus 1500 mAh @ 3,7 V (5,55 Wh brutto,
  ~4,44 Wh nutzbar) → **≈ 65 Dosiervorgänge pro Ladung**, bei 1× täglich also rund **2,2 Monate**.
  Die Energie je Dosis ist über den ganzen Entladezyklus praktisch konstant (0,067–0,071 Wh):
  bei niedrigerer Spannung läuft die Pumpe länger, zieht aber weniger Strom.
- **Warum keine 18650:** geschützte 18650 ist Ø18,85 × 69 mm und passt in die Wulst (40 mm tief),
  bringt aber ~3× Kapazität, die bei 65 Dosen pro Ladung niemand braucht. Option für später.

---

## 4b. Unterspannungsschutz — die Zelle nicht töten

Der Lader schützt **nicht** vor Tiefentladung. Belegt aus dem MCP73831-Datenblatt: der Chip hat
„Reverse Discharge Protection" (verhindert nur Rückstrom in den Lader) und eine UVLO von
**3,45 V Start / 3,38 V Stop** — die regelt aber nur, wann das *Laden* beginnt. Entladeschutz ist
nicht Teil des Chips. Deshalb vier Ebenen, von harmlos bis Notabschaltung:

| Ebene | Schwelle | Wirkt | Bauteil |
|---|---|---|---|
| 1 · Firmware | ~3,5 V Warnung, ~3,4 V Pumpstopp | normaler Betrieb, Telegram-Meldung | 200-k-Teiler + ADC (§6.3b) |
| 2 · Hardware | **3,08 V** (Datenblatt VTH 3,04/3,08/3,11 V) | sperrt die Pumpe **unabhängig von der Firmware** | **MAX809TEUR+T** `C16711` + Schottky |
| 3 · MCU tot | – | Gate-Pulldown 10 kΩ: hängender/gebrannter MCU = Pumpe AUS | R2 |
| 4 · Zelle | ~2,5 V (**nicht dokumentiert**) | letzte Notabschaltung | PCM in der EFASO-Zelle |

**Verschaltung von Ebene 2:** der RESET-Ausgang des MAX809 (aktiv low, push-pull, 12 µA) liegt über
eine Schottky-Diode am Gate-Knoten des Pumpen-MOSFET (Anode am Gate, Kathode an RESET). Fällt VBAT
unter 3,08 V, zieht RESET low und klemmt das Gate auf ~0,3 V — unter der Schwellenspannung des
AO3400A (0,65–1,45 V) → Pumpe aus, egal was die Firmware tut. Über 3,08 V liegt RESET auf VBAT,
die Diode sperrt, und der GPIO steuert normal.

→ kostet **ein zusätzliches Bauteil** (MAX809, 0,56 $, 13.783 lagernd) plus eine Diode, die wir
ohnehin im BOM haben. Den Gate-Widerstand R1 dafür von 220 Ω auf **4,7 kΩ** erhöhen: im Fehlerfall
(MCU will pumpen, Hardware sperrt) fließen dann 3 mA statt 14 mA durch den Klemmzweig; bei
Qg 6 nC bleibt das Schalten mit 20 kHz PWM unkritisch.

**Nicht doppelt bauen:** ein eigenes DW01A + FS8205A Schutzpaar ist bei JLC für 0,09 $ zu haben,
schaltet aber erst bei ~2,5 V ab — unterhalb unserer Hardware-Schwelle. Es dupliziert nur den
PCM der Zelle.

---

## 4c. Anlaufstrom 3 A gegen die Schaltung geprüft (14.09.2026)

**Frage:** Die CONQUERALL nennt **3 A Anlaufstrom** — trägt unsere Kette das?
(Werte: `hardware/schaltplan_v1.md` + `../docs/10_pcb-leiterbahnbreiten.md` + Datenblätter.)

**Ergebnis in einem Satz:** Der Strompfad trägt die 3 A kurzzeitig (MOSFET, Diode, Leiterbahnen),
aber **zwei Stellen können den Anlauf abschalten** — das PCM der Zelle (Overcurrent ~2–3 A) und der
Unterspannungswächter **MAX809 (3,08 V)** über den Spannungseinbruch. Das ist ein **Funktionsrisiko,
kein Sicherheitsrisiko**: nichts wird überlastet, die Pumpe bleibt nur stehen.

**1 · Der Anlaufstrom ist an unserer Zelle kleiner als 3 A.** Ein DC-Motor ist im Stillstand ohmsch:
`R_Motor = 5 V / 3 A = 1,67 Ω` → der Startstrom skaliert mit der Spannung:

| Zellspannung | 4,2 V | 4,0 V | 3,7 V | 3,4 V | 3,0 V |
|---|---|---|---|---|---|
| Anlaufstrom | 2,52 A | 2,40 A | 2,22 A | 2,04 A | 1,80 A |

**2 · Spannungseinbruch gegen die MAX809-Schwelle.** Serienwiderstände im Pumpenpfad (worst case):
Zelle 1500 mAh **80 mΩ** (typ. 60–100) · PCM 2× FS8205A **50 mΩ** · Q1 AO3400A @VGS 3,0 V **40 mΩ** ·
Leiterbahnen 0,5 mm über ~55 mm **64 mΩ** · JST-XH **20 mΩ** = **254 mΩ**.

| Zellspannung | Einbruch bei Anlauf | VBAT während des Anlaufs | gegen 3,08 V |
|---|---|---|---|
| 4,2 V | 0,64 V | 3,56 V | ✅ |
| 4,0 V | 0,61 V | 3,39 V | ✅ |
| 3,7 V | 0,56 V | 3,14 V | ✅ (knapp) |
| 3,4 V | 0,52 V | **2,88 V** | ❌ **MAX809 sperrt die Pumpe** |
| 3,0 V | 0,46 V | **2,54 V** | ❌ **MAX809 sperrt die Pumpe** |

→ **Unterhalb ~3,4 V Zellspannung startet die Pumpe nicht mehr** (mit 80 mΩ Zellwiderstand; bei
gesunden 60 mΩ verschiebt sich die Grenze auf ~3,1 V). Folge für die Firmware: der Feuchtewert
bleibt unverändert → die Diagnose würde fälschlich **„Tank leer / Pumpe verstopft"** melden.
Deshalb **VBAT während des Pumpvorgangs mitloggen** und Unterspannung getrennt melden (§4b Ebene 1).

**3 · PCM-Overcurrent der Zelle.** Typische 1S-PCMs mit **DW01A + FS8205A** schalten bei
**150 mV / (2 × RDS(on))** ab — mit 25–37 mΩ je FET also bei **2,0–3,0 A**. Der höchste Anlaufstrom
(2,5 A bei 4,2 V) liegt damit **genau auf der Schwelle**. Die EFASO-Zelle dokumentiert ihr PCM
**nicht** (§7) → Schwellwert am Prototyp messen.

**4 · Was die 3 A sicher trägt:**

- **Q1 AO3400A:** 5,2–5,8 A Dauerstrom im SOT-23 → 2,5 A Anlauf ✅; Verlust 0,36 W für die
  Anlaufdauer (~100 ms), im Dauerbetrieb bei 0,4 A nur **6 mW**.
- **D1 1N5819WS:** **1 A Dauer / 13 A Surge (8,3 ms)** — ⚠️ die oft zitierten 25 A gehören zur
  **DO-41-Version** 1N5819, nicht zur SOD-323-Variante. 3 A Freilaufpuls liegen trotzdem weit
  unter 13 A ✅.
- **Leiterbahnen 0,5 mm:** laut `docs/10` tragen sie 1,45 A bei 10 K **dauerhaft**; der Anlaufstrom
  fließt nur ~100 ms, Spannungsabfall dabei 141 mV ✅. Ein Dauerstrom von 3 A wäre **nicht** erlaubt —
  tritt aber nicht auf.
- **C3 100 µF: kein Anlaufschutz.** Er liefert 2,5 A nur **23 µs** lang (`t = C·ΔU/I`), das ist
  gegen den 100-ms-Motoranlauf wirkungslos. Nutzen hat er für HF-Störungen — dafür sitzt C11 100 nF
  direkt an den Pumpenklemmen.

**5 · Maßnahme: PWM-Softstart ist Pflicht (Firmware).** Mit einer Rampe über 100–300 ms steigt der
Strom nicht sprunghaft: bei **1,0 A** Anlaufstrom ist der Einbruch nur **0,25 V** → selbst aus 3,4 V
bleiben 3,15 V ✅, und die PCM-Schwelle wird sicher nicht erreicht. Der Pumpentreiber hängt am
GPIO2 über R1 4,7 kΩ / R2 47 kΩ und ist bereits PWM-fähig (20 kHz) → **keine Hardwareänderung,
nur Firmware**.

**6 · Konsequenz für die Pumpenwahl.** Die abgelöste OEM-Pumpe zog **0,4–0,54 A**: Einbruch ~0,14 V,
Anlauf unkritisch ohne jede Firmware-Maßnahme. Mit der CONQUERALL ist der Softstart **Bedingung**,
nicht Kür. Läuft die Pumpe an der Zelle trotzdem nicht sicher an, sind die Optionen in dieser
Reihenfolge: (a) Softstart + Messung, (b) Boost auf 5 V, (c) 2S, (d) zurück zur OEM-Pumpe (31,94 €).

---

## 5. Wulst-Maße (aus den finalen Bauteilen abgeleitet)

| Innenmaß | Wert | Bestimmt durch |
|---|---|---|
| Breite | **60 mm** | Pumpe + Wandungen, PCB ~52 mm, Zelle 37 mm |
| Tiefe (radial) | **40 mm** | Pumpe (Ø war 32 mm angenommen) + 2 × 2,5 mm Wand + Montagefreiheit |
| Höhe | **160 mm** (y = 90–250) | Pumpe + Halterung, darüber Platine + Zelle |
| Gesamtbreite Topf an der Wulst | **≈ 180 mm** | 140 mm + 40 mm |

Einbau von unten nach oben: **Pumpe** (Bauhöhe jetzt **42 mm** statt 44 mm, dadurch noch etwas mehr
Luft) → **Platine** → **Zelle** hinter/über der Platine.

⚠️ **Offener Punkt aus dem Pumpenwechsel (14.09.2026): Die CONQUERALL gibt keinen Durchmesser an.**
Die Wulst ist mit **Ø 32 mm** gerechnet worden (OEM-Pumpe). Die Bauhöhe ist mit 42 mm bestätigt, der
Ø muss **vor dem Einbau gemessen** werden — ist er größer als ~34 mm, wird die Wulsttiefe von 40 mm
knapp (Pumpe + 2 × 2,5 mm Wand + Montagefreiheit). Notfalls Wulst auf 44 mm Tiefe ziehen
(Gesamtbreite dann ≈ 184 mm).

**CAD-Parameter (`cad/params.py`):** dort stehen noch `pump_d = 27.8` · `pump_l = 66.8` ·
`pump_mount_cc = 50.0` · `pump_mount_d = 3.7` — die Werte der ursprünglichen Pumpe. Sie werden von
**keinem** Modul verwendet (nur Doku, per grep geprüft), die Wulst selbst ist parametrisch
unabhängig. Nach dem Ausmessen der CONQUERALL auf die gemessenen Werte ziehen (oder die Zeilen
löschen, damit sie nicht als Geometrie-Wahrheit missverstanden werden).

---

## 6. Konsequenzen für die PCB

1. **ESP32-C6-MINI-1** direkt auf der Platine (13,2 × 16,6 mm, `C5736265`), **Antenne am
   Platinenrand** (Punkt 6). Pflichtbeschaltung laut Espressif: **EN über RC-Glied 10 kΩ + 1 µF**,
   EN nie floaten lassen, Leitung kurz halten; **GPIO9 mit Pull-up** (Boot), **keine großen
   Kondensatoren an GPIO9** (sonst Download-Modus); am 3V3-Netz **22 µF Bulk + 2 × 0,1 µF**; am
   Stromeingang **≥ 10 µF + ESD-Diode** (Espressif Hardware Design Guidelines).
2. **Versorgung:** LDO **ME6211C33** (500 mA) — Pflicht, weil der ESP32-C6 im WLAN-TX **382 mA Peak**
   zieht (Espressif-Datasheet Tab. 6-4, selbst nachgeprüft) und Espressif ≥ 500 mA Ausgangsstrom
   verlangt. 200–250-mA-Regler (XC6206, HT7333, MCP1700) brownen bei TX aus; ein Pufferkondensator
   deckt nur sehr kurze Bursts.
2b. **Zelle + Laden:** **JST PH2.0-Buchse** + **MCP73831T-2** (4,20 V) + USB-C-Buchse mit
   2 × 5,1 kΩ (CC, USB-C-Pflicht) und USBLC6-2SC6 (ESD). USB-Daten gehen **nativ** auf
   **GPIO12 = D−** und **GPIO13 = D+** (Espressif) — kein USB-UART-Brückenchip nötig; optional
   22/33-Ω-Serienwiderstände vorsehen.
3. Pumpe: AO3400A Low-Side, **Gate 4,7 kΩ, Pulldown 47 kΩ** (Review 1), 1N5819 antiparallel, **100 µF Pufferelko** + 100 nF an den Klemmen (Review 3).
   Pumpe hängt **direkt an VBAT** — kein Wandler, kein Boost-Layout.
   ⚠️ **Anlaufstrom (14.09.2026, §4c):** die aktuelle Pumpe (CONQUERALL DC 5 V) zieht beim Anlauf
   **2,2–2,5 A** — der härteste Fall des ganzen Designs. Der 100-µF-Elko deckt davon nur **23 µs** ab
   (kein Anlaufschutz, nur HF-Bedämpfung), VBAT bricht über den 254-mΩ-Pfad um ~0,56 V ein, und damit
   kann der **MAX809 (3,08 V) die Pumpe selbst abschalten**, sobald die Zelle unter ~3,4 V liegt.
   → **PWM-Softstart (Rampe 100–300 ms) ist Pflicht** — reine Firmware, keine Hardwareänderung
   (GPIO2 → R1 → Gate; 20 kHz PWM ist ohnehin vorgesehen).
3b. **Zellspannung überwachen:** 200-k-Widerstand in 1:2-Beschaltung auf einen **ADC1**-Pin, plus
   **0,1 µF Filterkondensator** am ADC-Pin (Espressif-Empfehlung für ADC-Genauigkeit). Grundlage für
   Pumpstopp und Warnung in §4b. Der ADC des ESP32-C6 ist verrauscht → im Code vielfach mitteln und
   die Schwelle erst **im Ruhezustand** auswerten (während des Pumpens sackt die Spannung ab).
4. Sensor: 3-poliger JST-XH, **VCC über GPIO schaltbar** (nur während der Messung), AOUT auf ADC1.
5. Taster Reset/Boot, Status-LED sichtbar durch das LED-Fenster.
6. **Antenne — der Punkt, der die Mechanik betrifft.** Espressif wörtlich: „Ensure that the PCB
   antenna on the base board also has a sufficiently large clearance area inside the housing.
   A clearance of at least **15 mm** is recommended in all directions." Dazu: Antenne möglichst über
   den Platinenrand hinaus, sonst die Platine **beidseitig und unter der Antenne freischneiden**
   (nicht in der Mitte der Platine „freihöhlen"), Kupfer + dichte GND-Vias in Antennennähe, USB- und
   UART-Leitungen weit weg von der Antenne.
   → Für uns heißt das: **obere ~25 mm der Kammer bausteilfrei**, Modul mit der Antenne nach oben,
   und die **Wulstwand über der Antenne dünner** (6 mm → ~2 mm). Das ist eine Geometrie-Änderung in
   `cad/params.py`. Espressif schreibt außerdem vor, das **Endprodukt zu testen** (Durchsatz +
   Reichweite); fällt der Test schlecht aus, ist die Alternative das Modul **-1U** (`C20627095`) mit
   IPEX-Buchse und externer Antenne.
6b. **Espressif empfiehlt bei Akkubetrieb ausdrücklich einen Power-Monitor-Chip mit ~3,0-V-Schwelle** —
   genau das ist unser MAX809TEUR+T (3,08 V, §4b). Zwei unabhängige Quellen treffen sich hier.
7. **Kein XIAO mehr:** Lader, LDO und USB sind komplett durch eigene Bauteile ersetzt, die geplante
   V1/V2-Unterscheidung entfällt — es gibt **eine** Platine.

---

## 8. Optionale Sauerstoffpumpe (5 V) — recherchiert und ausgewählt (15.09.2026)

Die Sauerstoffpumpe hängt am zweiten Pumpenpfad (`Q3`, `R33`, `R34`, `D7`, `D8`, `C20`, Stecker **J16**
= JST-XH 2P aufrecht, Steuerung **IO22**) und wird aus dem neuen **5-V-Boost** (U8 MT3608) versorgt.
Damit sind die Randbedingungen fix: **5 V DC**, **≤ 1 A** (Pfad ausgelegt), Betrieb **im Intervall**.

### Empfehlung

**Mini USB Aquarium Luftpumpe, leise, mit Luftstein — Amazon `B0FXB5BMTT`, 8,48 €** (3,9 ★ / 45 Bewertungen)

| Kandidat | Preis | Bewertung | Spannung | Leistung | Förderleistung | Lautstärke | Lieferumfang |
|---|---|---|---|---|---|---|---|
| **`B0FXB5BMTT`** (Empfehlung) | **8,48 €** | 3,9 ★ | **5 V USB** | ~1 W | für 10–40 L | < 35 dB | **Pumpe + 1,15 m Silikonschlauch + Luftsprudler** |
| `B093GPMT1Z` | 9,99 € | 4,1 ★ | 5 V USB | 1 W | **210 L/h**, 150 g | leise (Keramikmotor) | Pumpe |
| `B0F1T8SPL3` | 9,00 € | 4,3 ★ | 5 V USB | 1 W | 130 g | „super silent" | Pumpe (Schlauch/Stein extra) |
| `B0GWMCWPNQ` | 8,99 € | 4,3 ★ | 5 V USB | 1 W | 130 g | leise (Keramikmotor) | Pumpe |
| `B0B82JX6Z4` (Colexy) | 7,29 € | 3,4 ★ | 5 V USB | 1 W | regelbar, 90 g | leise | Pumpe |
| ~~`B0FRFXMRDT`~~ (Pawfly Nano Silent) | 13,99 € | 4,2 ★ | **nicht als 5 V DC spezifiziert** | 1,3 W | 27 L/h (450 ml/min) | 30 dB (piezo) | Komplettset inkl. Rückschlagventil |
| ~~`B08MSYJRHC`~~ (Boxtech) | 32,99 € | 4,4 ★ | 2/5/8/10 W | zu groß/teuer | — | — | — |
| ~~`B0CKXKY31J`~~ (AQQA) | 37,99 € | 4,5 ★ | 4 Ausgänge, 10 W | **weit über dem Boost** | — | — | — |

**Warum der Empfehlungskandidat:** Er ist der einzige in der engen Auswahl, bei dem die Betriebsspannung
**explizit 5 V USB** ist *und* **Schlauch + Sprudelstein im Lieferumfang** sind — damit ist die Pumpe
sofort betriebsfertig, ohne Zusatzkauf. Er ist für **10–40 L** ausgelegt (unser Topf liegt deutlich
darunter) und laut Datenblatt **dauerbetriebsfähig**, was im Intervallbetrieb viel Reserve bedeutet.

**Pawfly (13,99 €, 30 dB) wäre der leiseste**, ist aber piezo-elektrisch und die Angebotsseite nennt
**keine 5-V-DC-Spannung** (Pawfly führt dieselbe Bauform auch als 230-V-Gerät) → für ein 5-V-Bordnetz
**nicht ohne Risiko**, deshalb nicht empfohlen.

### Strom- und Laufzeitrechnung (für die Auslegung)

| Größe | Wert |
|---|---|
| Leistung | 1 W bei 5 V → **0,20 A** am Boost-Ausgang |
| Strom aus der Zelle (3,7 V, η ≈ 0,85) | **≈ 0,32 A** |
| Zelle 1500 mAh, **Dauerbetrieb** | **≈ 4,7 h** bis leer |
| Intervall 6 × 15 min/Tag | 1,5 h/Tag, **≈ 0,5 Wh/Tag** — energetisch vernachlässigbar |
| Last für den Boost (1 A möglich) | 0,2 A → **unkritisch**, PWM-Softstart trotzdem sinnvoll |

### Anbindung (Hardware)

- Die Pumpe kommt mit **USB-A-Stecker**: Kabel abschneiden, **rot = +5 V**, **schwarz = GND**, auf
  **JST-XH 2P** crimpen (gleicher Steckertyp wie die Dosierpumpe an J4 → ein Crimp-Werkzeug).
- **Rückschlagventil** in die Luftleitung (sonst zieht Wasser in die Pumpe, wenn sie aus ist).
- **Membranpumpe braucht Frischluft** → außerhalb des Topfs montieren, Luftleitung in die Nährlösung.
- Betrieb über **IO22** (`PUMP2_EN`) mit **PWM-Softstart** (gleiche Rampe wie die Dosierpumpe).
- ⚠️ Energetisch gilt weiter: **nicht dauerhaft laufen lassen** — bei 1 W sind es ~4,7 h, das reicht
  für Intervall-Sauerstoffgabe, nicht für 24/7.

### Kaufquellen
- Empfehlung: https://www.amazon.de/dp/B0FXB5BMTT (8,48 €)
- Alternative kräftiger (210 L/h): https://www.amazon.de/dp/B093GPMT1Z (9,99 €)
- Alternative günstig: https://www.amazon.de/dp/B0B82JX6Z4 (7,29 €, regelbar)
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

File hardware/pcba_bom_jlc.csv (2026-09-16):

Comment | Designator | Footprint | LCSC Part # | Menge | Hinweis
IP2326 | U_CHG | VQFN-24-EP(4x4) | C2832094 | 1 | extended - 2S-Boost-Lader 8,4 V, ICHG = 90000/R_ISET = 0,90 A; EPAD ueber Vias an Kupferflaeche
HY2120-CB | U_PROT | SOT-23-6 | C116509 | 1 | extended - 2-Zellen-Schutz: Ueberladung 4,28 V, Tiefentladung 2,90 V/Zelle, Entlade-Ueberstrom 200 mV, Kurzschluss 1,0 V, Ruhestrom ~3 uA
PSMN4R2-30MLDX | Q_PROT1 Q_PROT2 | LFPAK33-8 | C179452 | 2 | extended - N-MOSFET 30 V, 5,7 mOhm max bei 4,5 V; je einer fuer Entladen (OD) und Laden (OC); Drain beider auf gemeinsamem Knoten
330R | R_PROT_VDD R_PROT_VC | 0805 | C17630 | 2 | basic - Typwerte des Schutz-IC (Datenblatt: 100-470 R fuer VDD/VC)
2k | R_PROT_CS | 0805 | C17604 | 1 | basic - CS-Widerstand (Datenblatt R3: 1-4 k, typ 2 k)
100R 0,25W | R_CB | 1206 | C17901 | 1 | basic - Balancing-Widerstand IP2326 (Pin 23 an Mittelabgriff). Im Fehlerfall 176 mW -> 1206/0,25 W statt 0805/125 mW
TPS3839G33DBZR | U7 | SOT-23-3 | C485802 | 1 | extended - Unterspannungswaechter 3,08 V, Iq 150 nA, Push-Pull; an R3a/R3b (1:2) = 6,16 V Pack
SY8113B ADC | U_BUCK5 | TSOT-23-6 | C78989 | 1 | extended - Buck 5 V/3 A, 500 kHz; Vout = 0,6 x (1 + 75/10) = 5,10 V
AP63203WU-7 | U_BUCK3 | TSOT-23-6 | C780769 | 1 | extended - Buck 3,3 V/2 A, 1,1 MHz, Iq 22 uA; Vout = 0,8 x (1 + 47/15) = 3,31 V
ESP32-C6-MINI-1 | U1 | SMD-53P | C5736265 | 1 | extended - Antenne am Platinenrand + 15 mm Freistellung
USBLC6-2SC6 | U6 | SOT-23-6L | C7519 | 1 | extended - ESD USB-Daten
AO3400A | Q1 Q_PUMP2 | SOT-23 | C20917 | 2 | basic - N-MOSFET Low-Side, je einer pro Pumpe (IO2, IO22)
AO3401A | Q2 Q_SENS | SOT-23 | C15127 | 2 | basic - P-Kanal-Load-Switch: VCC_EXT (Q2) + Sensorversorgung (Q_SENS)
1N5819WS | D1 D_FLY2 | SOD-323 | C191023 | 2 | basic - Freilaufdioden beider Pumpen (Kathode an +5 V)
LED-GREEN | D2 | 0805 | C2297 | 1 | basic - Status 525 nm, Vf 2,85 V
LED-RED | D5 D_LEDCHG | 0805 | C84256 | 2 | basic - Tank leer + Ladestatus (am LED-Pin des IP2326)
2.2uH Isat 5,0A DCR 58mR | L_CHG | SMD 4.6x4.1mm | C142096 | 1 | extended - Boost-Induktivitaet des Laders (2,2 uH @ 500 kHz laut Datenblatt)
4.7uH Isat 4,0A DCR 31mR | L_BUCK5 L_BUCK3 | SMD 6x6mm | C105660 | 2 | extended - Buck-Induktivitaet, gleicher Typ fuer beide Wandler
100nF | C1a C1b C9 C10 C11 C12 C13 C_BTN C_BST_CHG C_B5_BST C_B5_IN_HF C_B5_OUT_HF C_B3_BST C_B3_IN_HF C_B3_OUT_HF C_LIGHT C_PUMP2_EMI C_SPARE C_PROT_VDD C_PROT_VC | 0805 | C49678 | 20 | basic - Decoupling, ADC-Filter, EMI an den Pumpenklemmen, Bootstraps; zusaetzlich Schutz-IC-VDD/VC-Filter
1uF | C4 | 0603 | C15849 | 1 | basic - EN-RC-Glied
10uF 25V | C_CHG_IN C_CHG_VIN C_CHG_OUT | 0805 | C15850 | 3 | basic - Lader Ein-/VIN-/Ausgang (Datenblatt: >16 V, Keramik)
22uF 25V | C2 C_VSYS_A C_VSYS_B C_B5_IN C_B5_OUT C_B3_IN C_B3_OUT | 0805 | C45783 | 7 | basic - VSYS 2x, Modul-Bulk, Buck Ein-/Ausgang beider Wandler
100uF 16V | C3 | SMD D6.3x5.4 | C970684 | 1 | extended - Elko Pumpenpuffer, liegt jetzt auf +5V; POLARITAET beachten
1k | R1 R6 R_LEDCHG R_LIGHT_S R_SCL_S R_SDA_S R_SPARE_AIN R_SPARE_IO15 R_SPARE_IO16 R_SPARE_IO17 R_SPARE_IO21 R_SPARE_IO23 R_TANK R_GATE2 | 0805 | C17513 | 14 | basic - Gate-Serien, LED-Vorwiderstaende, Serienschutz aller Steckerleitungen
10k | R_EN R_BOOT R_GPIO8 R_BTN R_LIGHT R_FB5_BOT | 0805 | C17414 | 6 | basic - Pull-ups EN/GPIO9/GPIO8/Taster, Licht-Last, 5-V-Feedback unten
47k | R2 R_GATE R_GATE2_PD R_SENS_GATE | 0805 | C17713 | 4 | basic - Gate-Pulldowns beider Pumpen, Load-Switch-Pull-ups (VCC_EXT + Sensor)
200k | R_SENSE_TOP | 0805 | C17539 | 1 | basic - ADC-Teiler oben (1:3,94)
68k | R_UVSET R_SENSE_BOT | 0805 | C17801 | 2 | basic - R_UVSET (Lader-Eingang 4,35 V) + ADC-Teiler unten
75k | R_FB5_TOP | 0805 | C17819 | 1 | basic - Feedback oben des 5-V-Bucks
100k 1% | R_ISET R_EN_CHG | 0805 | C96346 | 2 | expand - R_ISET (Ladestrom, 1 % laut Datenblatt) + R_EN_CHG
51k | R3a R3b | 0805 | C17737 | 2 | basic - Waechter-Teiler 1:2 (51k/51k)
0.5R | R_VIN_CHG | 0805 | C28319 | 1 | expand - Filterwiderstand zum VIN-Pin des Laders (KEIN Shunt)
5.1k | R5a R5b | 0805 | C27834 | 2 | basic - USB-C CC1/CC2
220R | R4 | 0805 | C17557 | 1 | basic - Status-LED gruen
4.7k | R_SDA_PU R_SCL_PU | 0805 | C17673 | 2 | basic - I2C-Pull-ups an VCC_EXT
499R | R_UART | 0805 |  | 1 | DNP - NICHT BESTUECKEN (optionaler UART-Debug)
USB-C-16P | J5 | SMD | C165948 | 1 | extended - Buchse (Laden + Programmieren)
JST-XH-2P | J4 J16 J17 J18 | THT P2.5 aufrecht (Top-Entry) | C158012 | 4 | extended - Dosierpumpe (J4), Sauerstoffpumpe (J16), 5-V-Sensorausgang (J17), Akku-NTC (J18)
JST-XH-3P | J1 J2 | THT P2.5 aufrecht (Top-Entry) | C5258884 | 2 | extended - Akku 3-polig (B-/Mitte/B+) und Feuchtesensor; auf C5258884 (XH-3PA, 14.383 lagernd) umgestellt, C493416 ist nicht mehr auffindbar
Stiftleiste-1x3-2.54mm | J7 J9 J10 J11 J12 J13 J15 | THT P2.54 gerade | C2937625 | 7 | extended - XFCN PZ254V-11-03P; GND-VCC-SIG (VCC immer Pin 2)
Stiftleiste-1x4-2.54mm | J8 | THT P2.54 gerade | C2691448 | 1 | extended - XFCN PZ254V-11-04P; I2C GND-VCC-SDA-SCL
SW-SMD | SW1 SW2 | SMD-4P 5.1x5.1 | C318884 | 2 | basic - Reset + Boot
 | J6 | 2x Loch 1.0mm Raster 2.54mm |  | 1 | KEINE BESTUECKUNG - nur Lotpads fuer den externen Taster
5A traege 2410 | F1 | 2410 | C66503 | 1 | extended - Sicherung in der Pack-Plus-Leitung vor allen Verbrauchern (kurzschlussfest, ~17 ms bei ~56 A)
82k 1% | R_NTC_PAR | 0805 | C17840 | 1 | expand (Preferred, kein Feeder-Aufschlag) - Parallelwiderstand zum Akku-NTC, Datenblatt-Wert

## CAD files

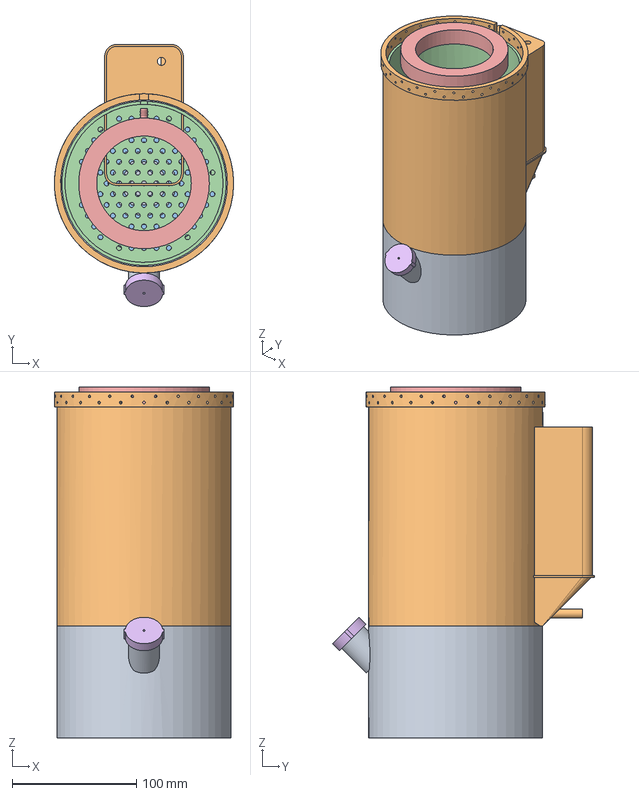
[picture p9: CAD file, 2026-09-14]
cad/export/assembly.step
144.0 x 210.6 x 282.0 mm
shell_lower
shell_upper
grid
inner_pot
distribution_ring
fill_cap

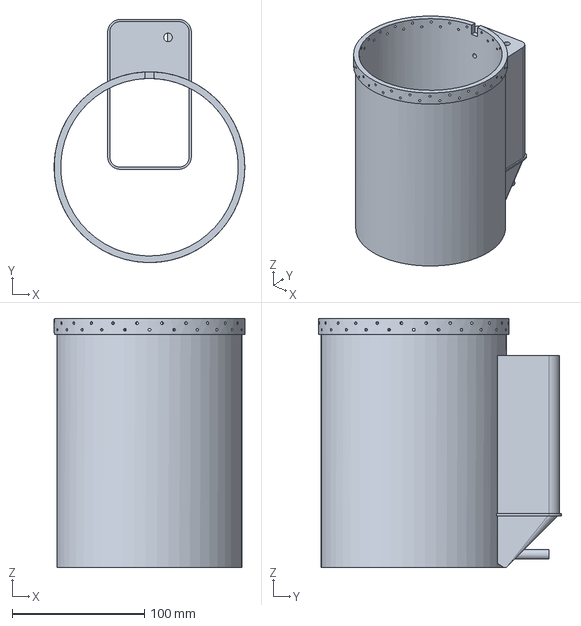
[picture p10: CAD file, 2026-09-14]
cad/export/shell_upper.step
144.0 x 183.6 x 188.0 mm

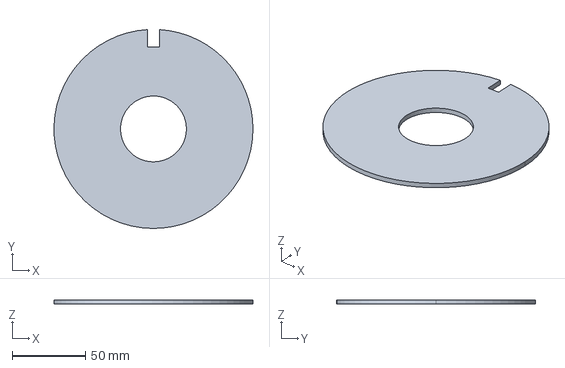
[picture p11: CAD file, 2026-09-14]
cad/export/cover.step
136.0 x 135.9 x 3.00 mm

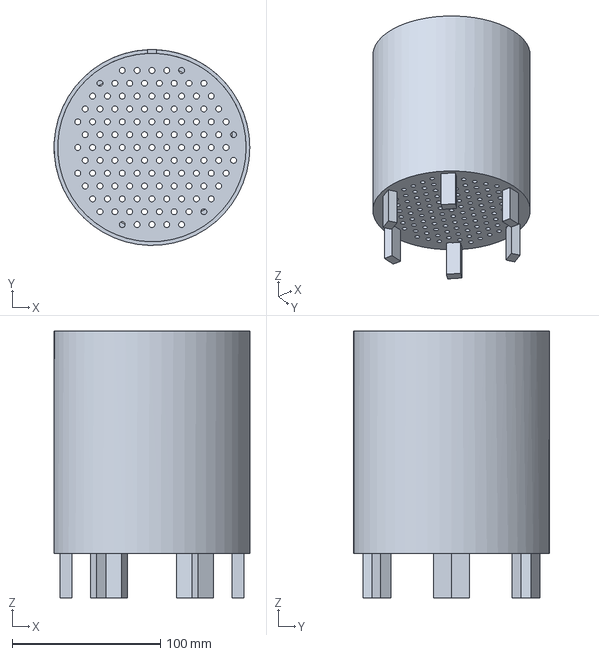
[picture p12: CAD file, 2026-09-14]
cad/export/inner_pot.step
131.9 x 132.0 x 180.0 mm

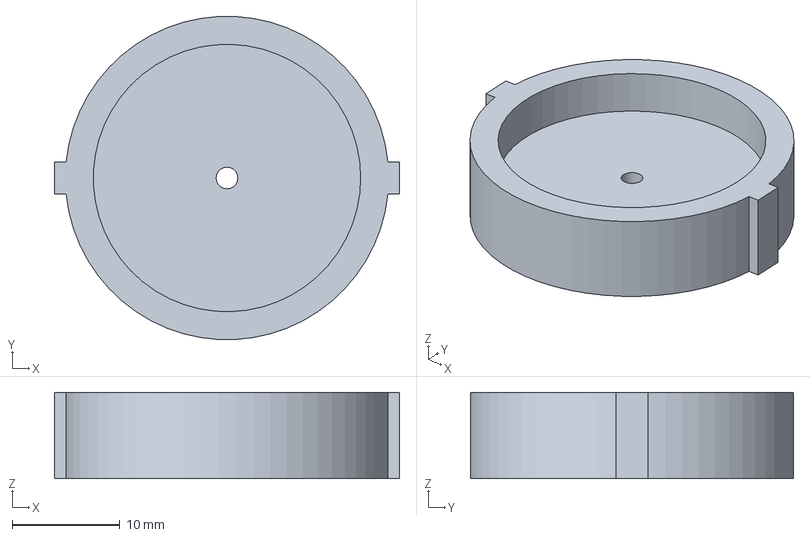
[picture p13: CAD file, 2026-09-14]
cad/export/fill_cap.step
32.0 x 30.0 x 8.00 mm

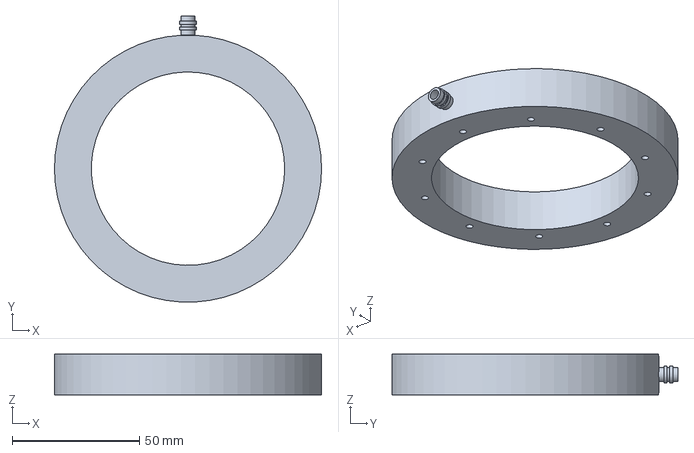
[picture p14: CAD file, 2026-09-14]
cad/export/distribution_ring.step
105.0 x 112.4 x 16.0 mm

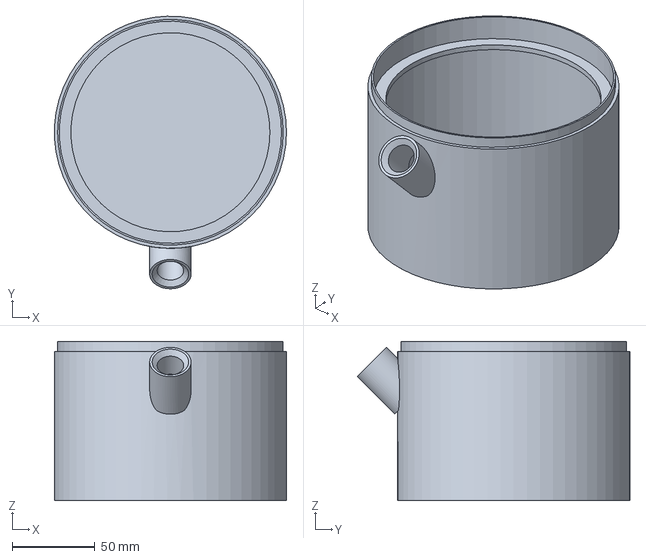
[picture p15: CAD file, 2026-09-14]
cad/export/shell_lower.step
139.9 x 164.4 x 96.0 mm

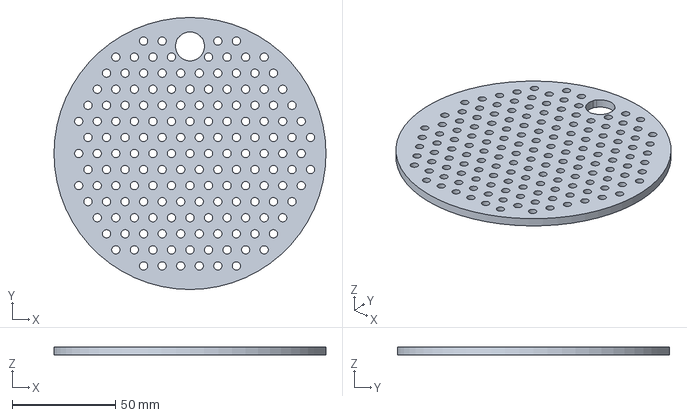
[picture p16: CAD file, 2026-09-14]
cad/export/grid.step
132.0 x 132.0 x 4.00 mm

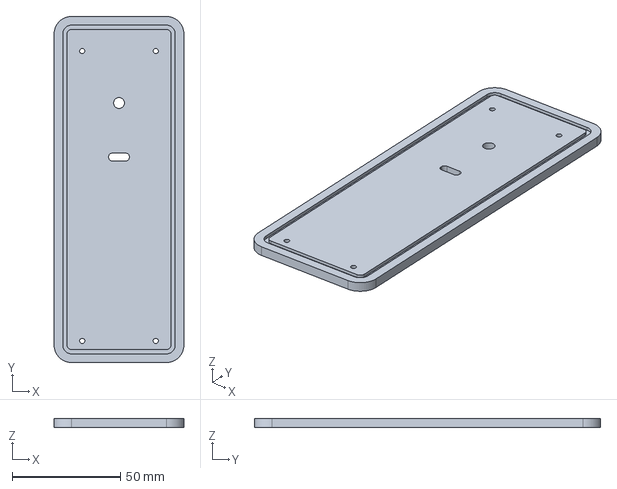
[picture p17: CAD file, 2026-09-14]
cad/export/wulst_lid.step
60.0 x 160.0 x 4.00 mm

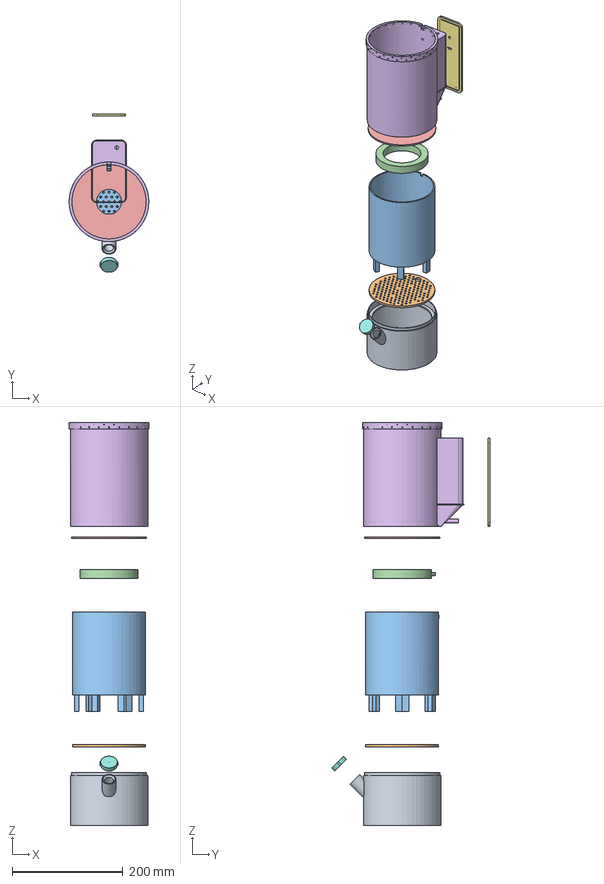
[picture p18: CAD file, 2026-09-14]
cad/export/exploded.step
144.0 x 286.3 x 728.0 mm
shell_lower
grid
inner_pot
distribution_ring
cover
shell_upper
wulst_lid
fill_cap

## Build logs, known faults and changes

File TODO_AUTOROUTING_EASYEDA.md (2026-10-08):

# To-Do-Liste: PCB-Autorouting mit Freerouting & EasyEDA (4 Lagen)

Stand: **Oktober 2026** · Projekt: **SmartGrowTopf_V1 (2S-Architektur, 4-Layer-Board)**  
Zugehörige Dokumente & Skripte:
* [`docs/10_pcb-leiterbahnbreiten.md`](file:///c:/Users/mgasc/Documents/cannabis-autopot/docs/10_pcb-leiterbahnbreiten.md) (Berechnungsgrundlagen nach IPC-2221A)
* [`docs/11_review-2s-umbau.md`](file:///c:/Users/mgasc/Documents/cannabis-autopot/docs/11_review-2s-umbau.md) (2S-Strom- und Leistungsanalyse)
* [`hardware/schaltplan_v1.md`](file:///c:/Users/mgasc/Documents/cannabis-autopot/hardware/schaltplan_v1.md) (Schaltplan und Pin-Belegung)
* [`hardware/easyeda/scripts/pcb_widths.py`](file:///c:/Users/mgasc/Documents/cannabis-autopot/hardware/easyeda/scripts/pcb_widths.py) (Prüfskript für Leiterbahnbreiten)

---

## 1. Freerouting: Download & Installation

Freerouting ist ein fortschrittlicher, quelloffener Autorouter für Leiterplatten, der über das standardisierte Specctra-DSN/SES-Format nahtlos mit EasyEDA zusammenarbeitet.

* **Offizielle Releases (Downloads):**  
  👉 [https://github.com/freerouting/freerouting/releases](https://github.com/freerouting/freerouting/releases)
* **Offizielle Installationsanleitung & Dokumentation:**  
  👉 [https://freerouting.org/](https://freerouting.org/) bzw. [Freerouting GitHub Installation Guide](https://github.com/freerouting/freerouting#installation)

### Installations-Optionen:
1. **Option A (Empfohlen für Windows): Standalone Installer**  
   * Lade aus den [Releases](https://github.com/freerouting/freerouting/releases) die aktuelle Datei `Freerouting-X.X.X-windows-x64.msi` herunter.
   * Der Windows-Installer bringt eine vorkonfigurierte Java-Laufzeitumgebung direkt mit. Nach der Installation kann Freerouting direkt per Startmenü geöffnet werden.
2. **Option B: Plattformunabhängiges JAR**  
   * Falls Java (Version 17 oder 21+) bereits installiert ist: Lade die Datei `freerouting-executable.jar` herunter.
   * Start über das Terminal / die PowerShell:
     ```powershell
     java -jar freerouting-executable.jar
     ```

---

## 2. Das 4-Lagen-Schichtenmodell (JLCPCB JLC04161H)

* **Layer 1 (TopLayer, 1 oz / 35 µm):**  
  Bauteile, ESP32-C6-Antenne, differenzielles USB-Paar (`USB_DP`/`USB_DM`), lokale Leistungsbahnen/-flächen.
* **Layer 2 (Inner1 – Solide GND-Plane, 0.5 oz / 17.5 µm):**  
  **100 % durchgehende Massefläche.** Keine Signalbahnen hier durchrouten! Direkte Wärmesenke und HF-Rückstrompfad für das EPAD des IP2326.  
  *(⚠️ Ausnahme: Absolutes Keepout unter der ESP32-C6-Antenne!)*
* **Layer 3 (Inner2 – Power Plane / Split Plane, 0.5 oz / 17.5 µm):**  
  Versorgungsflächen (`VBAT`, `+5V`, `+3V3`) und kreuzungsfreie Signalüberquerungen.
* **Layer 4 (BottomLayer, 1 oz / 35 µm):**  
  Zusätzliche Signale, Testpunkte und rückseitige GND-Kühlflächen.

---

## 3. Übersicht der Designregeln & Leiterbahnbreiten

> [!IMPORTANT]
> **Thermische Besonderheit bei 4 Lagen (IPC-2221A):**  
> Innenlagen kühlen im Epoxidharz schlechter ab als Außenlagen ($k = 0{,}024$ innen vs. $k = 0{,}048$ außen).  
> **Leistungspfade (`VBAT`, `+5V`) mit 2,8–3 A daher bevorzugt auf Layer 1 (Top, 1 oz) führen ODER auf Layer 3 als breite Kupferfläche (Polygon Pour) anlegen!**

| Netz / Funktion | Sollbreite (Außenlage) | Min. (Neck-Down) | Max. Strom | Lage & Routing-Vorgabe |
|---|---|---|---|---|
| **VBAT / PACK_PLUS** | **≥ 1,00 mm** (40 mil) bzw. **Fläche** | 0,50 mm (nur am Pad) | **~2,8 A** | TopLayer (1 oz) oder Layer 3 als Fläche. Speist 5V-Buck für 3-A-Pumpenanlauf. |
| **+5V** (Pumpenschiene) | **≥ 1,00 mm** (40 mil) bzw. **Fläche** | 0,50 mm | **3,0 A** | TopLayer direkt zu C3, Q1, Q3, J4, J16. Deckt den Motoranlauf ab. |
| **PUMP_N / PUMP2_N** | **0,50 mm** (20 mil) | 0,40 mm | 3,0 A (Puls) / 0,6 A Dauer | TopLayer. Drain von Q1/Q3 → J4/J16. (Nicht als simples Signal einstufen!). |
| **VBUS** (USB 5 V) | **0,60 – 0,80 mm** | 0,50 mm | **~1,6 A** | Ladeeingangsstrom zu IP2326 Pin 13. |
| **+3V3** (Logik-Rail) | **0,40 mm** (16 mil) | 0,25 mm | 0,50 A (382 mA TX-Peak) | Vom AP63203-Buck zum ESP32-C6-Modul (Layer 1 oder Layer 3). |
| **VCC_EXT** | **0,50 mm** (20 mil) | 0,25 mm | ~0,10 A | Geschaltete Sensorversorgung (Q2 → J8/J9–J15). |
| **GND** | **Solide Ebene (Layer 2)** | Vias direkt ins Pad | bis 3 A | Layer 2 als Plane. Kurze Stiche/Vias direkt an die Pads (keine Leiterschleifen). |
| **USB_DP / USB_DM** | **0,23 mm / 0,20 mm Gap** | 0,15 mm | 12 Mbit/s FS | **90 Ω diff. Impedanz** mit Layer 2 (GND) als Referenz! Parallel und symmetrisch. |
| **Signale** (I²C, ADC, GPIOs) | **0,25 mm** (10 mil) | 0,15 mm | < 20 mA | Layer 1 oder Layer 4. |

### JLCPCB 4-Lagen Standardparameter
- **Min. Trace / Spacing:** `0,127 mm` (5 mil) – wir nutzen 0,25 mm für maximale Prozesssicherheit.
- **Via-Bohrung / Pad:** `0,30 mm Drill / 0,60 mm Pad`.
- **Clearance (Abstand):** `0,20 mm` (empfohlen), minimal `0,15 mm`.

---

## 4. Das Neck-Down-Verfahren & der Freerouting „Stub“-Trick

### Warum scheitert Freerouting ohne Vorbereitung?
Freerouting hält sich strikt an die eingestellten Netzklassen. Wenn für `VBAT` eine Breite von 1,0 mm vorgegeben ist, versucht Freerouting mit dieser 1,0-mm-Bahn bis auf das 0,25 mm kleine Pad des IP2326 (QFN-24, Pinabstand 0,5 mm) zu fahren. Das verletzt sofort die Abstandsregeln (Clearance) zu den Nachbarpins, und Freerouting kann das Netz nicht fertigstellen.

### Die Lösung: Manuelle Stubs vor dem DSN-Export
1. **Kurze Ausfädelungen (Stubs) in EasyEDA zeichnen:**
   * Am **IP2326 (`U_CHG`)**: Pins **21 & 22** (VOUT/VBAT) gemeinsam mit einer kurzen 0,5-mm-Bahn ca. 0,8 mm weit aus dem Gehäuse herausziehen.
   * An den **MOSFETs (Q1/Q3, SOT-23)** und **Buck-Reglern (TSOT)**: Die Leistungspads ebenfalls mit 0,5 mm kurz (ca. 0,5–1 mm) herausführen.
2. **Stubs sperren (`Lock: Yes`):**
   * Alle gezeichneten Stummel markieren und im Eigenschaften-Panel auf **`Locked: Yes`** setzen.
3. **USB-Paar & Thermal Vias sperren:**
   * `USB_DP`/`USB_DM` manuell verlegen (0,23 mm Bahn, 0,20 mm Gap) und sperren.
   * Die 4–6 Thermal Vias im EPAD des IP2326 setzen und sperren.
4. **Ergebnis in Freerouting:**  
   Freerouting übernimmt gesperrte Elemente aus der DSN-Datei als feste (`FIXED`) Hindernisse und dockt mit der vollen 1,0-mm-Leiterbahn nahtlos an den gesperrten 0,5-mm-Stubs an!

---

## 5. Der Datenaustausch-Workflow (EasyEDA ⇄ Freerouting)

```
[EasyEDA PCB] 
     │  Export Specctra DSN
     ▼
[projekt.dsn]
     │  In Freerouting laden & autorouten
     ▼
[Freerouting]
     │  Export Specctra Session
     ▼
[projekt.ses]
     │  In EasyEDA importieren
     ▼
[EasyEDA PCB] ──► Flächen fluten, Teardrops, DRC
```

### Schritt-für-Schritt-Anleitung:

#### 1. In EasyEDA: DSN-Export
1. Netzklassen und Breiten einstellen (`Design` → `Design Rule...`).
2. Stubs, USB-Paar und Thermal Vias vorab zeichnen und auf **`Locked: Yes`** setzen.
3. Datei exportieren: **`File` → `Export` → `Specctra DSN...`** (z. B. als `SmartGrowTopf_V1.dsn` speichern).

#### 2. In Freerouting: Laden & Routing
1. Freerouting starten und auf **`Open Design`** klicken → `SmartGrowTopf_V1.dsn` auswählen.
2. **Lagen konfigurieren (`Rules` → `Layers`):**
   * `TopLayer` und `BottomLayer`: Routing **aktiviert**.
   * `Inner1` (GND): **Deaktivieren / als Plane deklarieren** (damit Freerouting dort keine Signalbahnen hindurchlegt, sondern nur Vias anbindet).
   * `Inner2`: Optional für Power/Signal freigeben.
3. Auf **`Autoroute`** klicken. Freerouting beginnt mit Ripup-and-Retry.
4. Nach Erreichen von 100 %: Auf **`Postroute`** klicken (entfernt überflüssige Vias und glättet Leiterbahnen).
5. Sitzung exportieren: **`File` → `Export Specctra Session File`** → speichert `SmartGrowTopf_V1.ses`.

#### 3. Zurück in EasyEDA: SES-Import & Finish
1. In EasyEDA: **`File` → `Import` → `Specctra Session...`** wählen und die `SmartGrowTopf_V1.ses` laden.
2. Die fertig gerouteten Bahnen und Vias werden direkt in das Board geladen.
3. **Flächen gießen:**
   * Layer 2 als durchgehende `GND`-Plane fluten.
   * Layer 1 & 4 Freiflächen mit `GND` füllen.
4. **Teardrops hinzufügen:** `Tools` → `Teardrop` ausführen.
5. **Prüfen:** DRC ausführen und Python-Prüfskript starten.

---

## 6. To-Do-Checkliste (Phase A bis E)

### Phase A: Vorbereitung in EasyEDA (Vor dem DSN-Export)
- [ ] **A.1 Freerouting installieren:**
  - Standalone-Installer von [GitHub Releases](https://github.com/freerouting/freerouting/releases) oder JAR heruntergeladen und funktionsfähig.
- [ ] **A.2 Netzliste & 4-Layer-Stackup:**
  - 2S-Netzliste (68 Netze) aktiv.
  - Lagen auf 4 Layers gestellt (`TopLayer`, `Inner1` GND, `Inner2` Power, `BottomLayer`).
- [ ] **A.3 Antennen-Keepout auf ALLEN 4 LAGEN:**
  - 15 mm Freiraum um die ESP32-C6-Antenne auf Layer 1, 2, 3 und 4 kupferfrei halten!
- [ ] **A.4 Feste Bauteile platzieren & sperren:**
  - USB-C `J5`, ESP32-C6 Modul, `U_CHG` (IP2326), `U_BUCK5`, `U_BUCK3`, Stecker `J1`, `J4`, `J16`, `J18`.
- [ ] **A.5 Thermal Vias & USB-Paar manuell vor-routen & sperren:**
  - 4–6 Thermal Vias im EPAD von `U_CHG` direkt zu Layer 2 platzieren → `Locked: Yes`.
  - `USB_DP` / `USB_DM` manuell auf TopLayer verlegen (0,23 mm / 0,20 mm Gap) → `Locked: Yes`.
- [ ] **A.6 Neck-Down-Stubs zeichnen & sperren:**
  - Pins 21 & 22 am IP2326 mit 0,5 mm Stub herausführen → `Locked: Yes`.
  - Leistungspins an Q1, Q3, U_BUCK5 mit 0,5 mm herausführen → `Locked: Yes`.
- [ ] **A.7 Netzklassen in EasyEDA definieren:**
  - `HIGH_CURRENT` (1,00 mm), `POWER_MEDIUM` (0,50 mm), `DEFAULT` (0,25 mm).

---

### Phase B: DSN-Export & Freerouting-Durchlauf
- [ ] **B.1 DSN-Datei exportieren:** In EasyEDA `File` → `Export` → `Specctra DSN...`.
- [ ] **B.2 In Freerouting öffnen:** DSN laden und Lagenregeln prüfen (`Inner1` GND nicht für Signale nutzen).
- [ ] **B.3 Autoroute starten:** Warten bis 100 % Complete erreicht ist.
- [ ] **B.4 Postroute / Optimierung ausführen:** Vias reduzieren und Ecken glätten lassen.
- [ ] **B.5 SES-Datei exportieren:** `File` → `Export Specctra Session File (.ses)`.

---

### Phase C: SES-Import & Fertigstellung in EasyEDA
- [ ] **C.1 SES-Datei importieren:** In EasyEDA `File` → `Import` → `Specctra Session...`.
- [ ] **C.2 Sichtprüfung Neck-Down:** Saubere 45°-Übergänge von den gesperrten Stubs zu den 1,0-mm-Bahnen prüfen.
- [ ] **C.3 Kupferflächen fluten:**
  - Layer 2 als durchgehende `GND`-Plane fluten.
  - Layer 3: Power-Flächen (`VBAT`, `+5V`, `+3V3`) gießen.
  - Layer 1 & 4: Restflächen mit `GND` füllen.
- [ ] **C.4 Teardrops generieren:** In EasyEDA `Tools` → `Teardrop` anwenden.

---

### Phase D: Verifikation & Abnahme (Definition of Done)
- [ ] **D.1 EasyEDA DRC:** `Design Rule Check` liefert 0 Fehler / 0 Abstandsverletzungen.
- [ ] **D.2 Skript-Prüfung:**
  ```bash
  python hardware/easyeda/scripts/pcb_widths.py --check
  ```
  Muss Exit 0 liefern.
- [ ] **D.3 Antennen-Kontrolle:** Keepout auf allen 4 Lagen intakt.
- [ ] **D.4 Stecker & Polung:**
  - J1 (Akku 2S: 1 = BAT-, 2 = MID, 3 = BAT+).
  - J4/J16 (Pumpen), J5 (USB-C), C3 (Elko-Polarität).

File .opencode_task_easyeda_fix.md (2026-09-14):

# AUFGABE: Nachbesserung EasyEDA-Generatoren — echte UUIDs + Lötpads TP7–TP11 wirklich platzieren

## 1. Geräte-UUIDs der neuen Bauteile sind jetzt live aufgelöst (Platzhalter ersetzen)

`easyeda --project "SmartGrowTopf_V1" lib by-lcsc --lcsc C157925,C15127` hat geliefert
(live, 13.09.2026, Bibliothek `0819f05c4eef4c71ace90d822a990e87`):

| LCSC | Hersteller-Typ | device uuid | Footprint |
|---|---|---|---|
| **C157925** (J8) | JST S4B-XH-A(LF)(SN) | **`a65b5fe9c5534a8fbb37396bd1bbe8a2`** | `CONN-TH_S4B-XH-A-LF-SN` |
| **C15127** (Q2) | AOS AO3401A | **`f58385f66b144586baef3753ba84f65d`** | `SOT-23_L2.9-W1.3-P1.90-LS2.4-BR` |

Die deterministisch abgeleiteten Platzhalter-UUIDs in `build_ir.py` (`NEW_PARTS`) sind durch diese
echten Werte zu ersetzen. Kommentar dazu: die Ableitung kann bleiben, falls je ein Bauteil
nachkommt — aber die tatsächlichen UUIDs müssen Vorrang haben.

## 2. TP7–TP11 **müssen** platziert und verdrahtet werden

Die aktuelle Fassung schiebt TP7–TP11 per `raw/no_place.json` aus Platzierung **und** Autoconnect
heraus — Begründung war die IR-Zählung. Das widerspricht dem Zweck: der Nutzer will diese GPIOs
**als Lötpads auf der Platine** haben. Ohne Schemapad gibt es kein PCB-Pad.

**Vorgehen wie bei TP1–TP6** (die sind bereits platziert, gleiche Bauart):
- Geräte-UUID des Testpunkt-Symbols wie TP1–TP6: **`1d9ad61565194f66a2bb1c832c938c3d`**
- `raw/no_place.json` auf die tatsächlich ausgeschlossenen Teile reduzieren (TP7–TP11 entfernen)
- in `plan_layout.py`/`place_all.sh` mit sinnvollen Koordinaten im MCU-Block platzieren
  (nicht überlappend, Pin-Fan von U1 beachten — lieber etwas mehr Abstand)
- in die Autoconnect-Specs aufnehmen (`kind: netport`), Netze laut Netzliste:

| Pad | Netz | Gegenstück |
|---|---|---|
| TP7 | `SPARE_IO15` | U1 Pin 20 (IO15) |
| TP8 | `UART_TX` | U1 Pin 31 (TXD0), dort auch R_UART/TP1 |
| TP9 | `UART_RX` | U1 Pin 30 (RXD0), dort auch TP2 |
| TP10 | `SPARE_IO22` | U1 Pin 28 (IO22) |
| TP11 | `SPARE_IO23` | U1 Pin 29 (IO23) |

## 3. Nachweis (erneut belegen)

- Alle Generatoren laufen mit `python3` durch, Exit 0, **keine Live-CLI-Aufrufe**.
- Selbstkonsistenzprüfung IR ↔ `hardware/schaltplan_v1_netzliste.csv`: **0 Abweichungen**,
  und diesmal **inkl. TP7–TP11** (Zahl der Verbindungen nennen — vorher 190 mit 23 übersprungen).
- `raw/place_all.sh` enthält **75** Platzierungszeilen (70 + 5 Lötpads) — Zahl belegen.
- Kurzbericht: was geändert, welche Zahlen, was weiterhin offen ist.

## Regeln

- Nur Dateien unter `hardware/easyeda/` ändern. Keine Live-Aufrufe der `easyeda`-CLI.
- Ehrlich melden, wenn eine Zählung nicht aufgeht — nicht durch Ausschluss von Bauteilen glätten.

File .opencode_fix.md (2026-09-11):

# Nacharbeit Gehäuse-CAD — zwei Befunde aus der Vermessung

Das Modell steht und alle Teile rendern. Der Auftraggeber hat die STL **nachgemessen** und dabei
zwei Punkte gefunden. Arbeite in `~/Projekte/cannabis-autopot`, lies zuerst `case/README.md` und
`case/params.scad`. Ändere **nur** das, was hier steht — alle übrigen Maße sind freigegeben und
dürfen nicht wandern.

## Befund 1 — Schlauchstutzen am Verteilerring durchdringt die Topfwand

Gemessen am gerenderten `distribution_ring.stl`:

- Der Ringkörper liegt bei Radius 52,5 mm (Ø 105, wie spezifiziert). OK.
- Der **Schlauchstutzen ragt aber 12,1 mm radial heraus** → max. Radius **64,6 mm**.
- Der Innentopf hat innen Radius **63,5 mm** (Ø 127) → der Stutzen steckt **1,1 mm in der Wand**.
- Zusätzlich zeigt der Stutzen in **+X**, der Druckschlauch kommt aber aus der Wulst in **+Y**
  (dort liegt `pressure_y = 98`, der Ring müsste also so gedreht werden, dass sich beide treffen).

**Zu beheben:**
1. Stutzen auf **max. 8 mm** kürzen → max. Radius ≤ 60,5 mm, mindestens 3 mm Luft zur Topfwand.
2. Stutzen in **Richtung der Wulst (+Y)** legen, nicht +X, damit der Schlauch gerade verläuft.
3. Am Innentopf-Rand oben einen **Schlauchdurchlass** vorsehen (≥ 6 × 6 mm, ebenfalls +Y), damit
   der Druckschlauch von der Wulst über den Rand zum Ring geführt werden kann, ohne gequetscht
   zu werden. Der Sensorkabel-Ausschnitt am Kragen bleibt, wo er ist — Kabel und Schlauch dürfen
   sich nicht denselben Ausschnitt teilen.

Nach der Änderung: **max. Radius des Rings messen und im README als Zahl nennen** (nicht schätzen).

## Befund 2 — es fehlt eine Zusammenbau-Ansicht

`case.scad` legt die Teile nur nebeneinander (Druckplatte). Dadurch ist keine Kollisionsprüfung
möglich. Lege **`assembly.scad`** an, die den montierten Zustand zeigt:

- Innentopf an seinem Platz (Füße auf dem Rost, Unterkante `pot_z0`),
- Außenschale (unteres + oberes Segment) in Position,
- Verteilerring **auf der Substratoberfläche** (z = Oberkante Innentopf),
- Sensor als einfacher Marker (Stab Ø 5 mm) bei **r = 55 mm, 75 mm tief**, plus Kabelweg,
- Schlauchweg von der Wulst über den Rand zum Stutzen als Linie/Kette.

Ziel: man muss sehen und messen können, dass Ring und Sensor sich nicht ins Gehege kommen und
dass der Schlauch ohne Knick über den Rand passt.

## Verifikation (Pflicht)

- Jedes geänderte Teil **und** `assembly.scad` mit dem Projekt-Renderer rendern
  (`node tools/oscad-render/render.mjs case/<teil>.scad -o case/export/<teil>.stl`) — alle
  Renders müssen mit Exit-Code 0 durchlaufen.
- `case/README.md` aktualisieren: neue Stutzenlänge, max. Radius als gemessene Zahl, Eintrag für
  `assembly.scad` in der Dateitabelle, und die Montagereihenfolge um den Schlauchweg ergänzen.
- Zum Schluss knapp berichten: geänderte Dateien, gemessene Zahlen, Render-Kommandos mit Ergebnis.
  **Nicht committen** — das macht der Auftraggeber.

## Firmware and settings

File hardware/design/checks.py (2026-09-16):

"""Design-Regelpruefungen fuer den Schaltplan V1 (2S-Umbau, 16.09.2026).

Jede Pruefung liest die echten Dateien ueber :mod:`design.circuit` und liefert
ein :class:`CheckResult` mit (name, bestanden, ist_wert, soll_kriterium,
begruendung).  Hart verdrahtet sind nur Datenblatt-Grenzwerte; die Quelle steht
jeweils in der Begruendung.  Systemgroessen kommen aus ``circuit.SYSTEM`` und
werden von :func:`check_system_quellen` gegen die Dokumente belegt.
"""
from __future__ import annotations

import re
from collections import defaultdict, namedtuple

from . import circuit

CheckResult = namedtuple("CheckResult", "name bestanden ist soll begruendung")


class PruefFehler(Exception):
    """Werkzeugfehler: Pruefmodell und Netzliste passen nicht zusammen.

    Anders als :class:`circuit.CircuitError` ist das **kein Design-Fehler**:
    Eine Pruefung darf gar nicht erst laufen, weil sie einen Pin-/Bauteilnamen
    verwendet, den die Netzliste nicht kennt.  Der Bericht weist das getrennt
    als "Werkzeugfehler" aus (eigener Exit-Code) und zaehlt es nicht als
    "Pruefung fehlgeschlagen" -- sonst haelt man einen veralteten Pruefstand
    faelschlich fuer einen bestandenen oder fehlgeschlagenen Test.
    """

# ===========================================================================
# Datenblattgrenzen (jede mit Quelle)
# ===========================================================================

# --- IP2326 (Injoinic, LCSC C2832094), Datenblatt V1.11 --------------------
IP2326_ICHG_K = 90000.0          # ICHG = 90000/R_ISET[Ohm], §"充电电流设置" S. 11
IP2326_ICHG_MAX_A = 1.5          # §7 Elektrische Eigenschaften S. 4
IP2326_VSET_OPEN_V = 8.4         # VSET offen ⇒ 8,4 V (8,3-8,5), §7/S. 4
IP2326_VSET_TOL_V = 0.1          # Toleranz 8,3-8,5 V
IP2326_EFF = 0.94                # Wirkungsgrad 94 % (5 V→8 V/1 A), §1 S. 1
IP2326_VIN_MIN_V = 4.5           # Eingang 4,5-9,5 V, S. 3
IP2326_VIN_MAX_V = 9.5
IP2326_CELL_MAX_V = 4.2          # Li-Ion-Ladeschluss 4,2 V/Zelle
IP2326_CHARGE_PHASES = (         # §9, S. 9: Phasen-Stroeme
    (3.7, 0.050),                # < 3,7 V -> 50 mA
    (6.0, 0.100),                # 3,7-6 V -> 100 mA
)
IP2326_8V8_V = 8.8               # Variante IP2326_8V8: 8,8 V Ladeschluss
                                 # (fuer Li-Ion unzulaessig, schaltplan §3.1)

# --- HY2120-CB (HYCON, LCSC C116509), 2-Zellen-Schutz-IC -------------------
# Schwellen stehen im HY2120-Datenblatt und sind in schaltplan_v1.md §3.1/§6.3
# belegt; die Pruefungen check_schutz_schwellen / check_schutz_ueberstrom lesen
# sie zusaetzlich woertlich aus dem Dokument (keine Tautologie).
HY2120_OC_DELAY_MS = 10.0        # interne Verzoegerung Ueberstrom, §3.1

# --- PSMN4R2-30MLDX (Nexperia, LCSC C179452), Schalterpaar -----------------
PSMN4R2_RDSON_MAX_OHM = 5.7e-3   # 5,7 mOhm max bei V_GS = 4,5 V (schaltplan
                                 # §3.1: PSMN4R2-30MLDX, LFPAK33-8), 4,3 mOhm
                                 # bei 10 V. Paar = 2 x 5,7 mOhm = 11,4 mOhm.
SCHUTZ_DAUER_DROP_MAX_V = 0.050  # Auslegungsgrenze: Abfall des Paares bei
                                 # Dauerlast <= 50 mV (Review-Vorgabe).
BUCK_INRUSH_EFF = 0.90           # Buck-Wirkungsgrad beim Anlauf (bom_entscheidung.md:
                                 # "Buck aus 2S (eta 0,90)")

# --- SY8113B (Silergy, C78989), Datenblatt AN_SY8113B ----------------------
BUCK5_VIN_MIN_V, BUCK5_VIN_MAX_V = 4.5, 18.0
BUCK5_IOUT_MAX_A = 3.0          # 3 A Ausgang, S. 1
BUCK5_FSW_HZ = 500e3            # 500 kHz
BUCK5_EN_HIGH_V = 1.5           # EN High-Schwelle, "Do not float"
BUCK5_EN_LOW_V = 0.4
BUCK5_UVLO_V = 4.5              # Input-UVLO
BUCK5_VALLEY_MIN_A, BUCK5_VALLEY_MAX_A = 3.0, 4.25   # Stromgrenzen (EC)
BUCK5_PEAK_A = 6.0              # Top-FET-Peak
L_BUCK_ISAT_A = 4.0             # PRS6045-Datenblatt: Isat 4,0 A (L_BUCK5/3)

# --- AP63203 (Diodes, C780769), Datenblatt DS41326 -------------------------
BUCK3_VIN_MIN_V, BUCK3_VIN_MAX_V = 3.8, 32.0
BUCK3_IOUT_MAX_A = 2.0          # 2 A
BUCK3_FSW_HZ = 1.1e6            # 1,1 MHz
MODULE_VDD33_MIN_V = 3.0        # Espressif ESP32-C6-MINI-1: V_DD33 3,0-3,6 V
MODULE_VDD33_MAX_V = 3.6

# --- TPS3839G33 (TI, C485802), Datenblatt SBVS193D -------------------------
TPS3839_VIT_MIN_V, TPS3839_VIT_MAX_V = 3.003, 3.126   # negativ, S. 7
TPS3839_VIT_NOM_V = 3.08        # im Projekt verwendeter Wert
TPS3839_HYST_V = 0.031          # Hysterese 31 mV
TPS3839_IQ_TYP_UA, TPS3839_IQ_MAX_UA = 0.15, 0.5      # Iq 150 nA typ / 500 nA max
TPS3839_VDD_MIN_V, TPS3839_VDD_MAX_V = 0.9, 6.5       # V_DD-Bereich
TPS3839_VOL_V = 0.4             # V_OL <= 0,4 V bei I_OL = 2 mA (2,8-6,5 V)
TPS3839_IOL_A = 2e-3            # Ausgangsstrom 2 mA
TPS3839_VOH_DROP_V = 0.4        # V_OH >= V_DD - 0,4 V
TPS3839_RESET_DELAY_MS = 200.0  # Reset-Delay 200 ms
WATCHDOG_TRIP_MIN_V, WATCHDOG_TRIP_MAX_V = 6.0, 6.6   # Ziel: 2 x 3,0 .. 2 x 3,3 V

# --- 1N5819WS (C191023) -----------------------------------------------------
DIODE_VF_SCHOTTKY_V = 0.3       # Flussspannung bei kleinem Strom (Auslegung)

# --- ADC (Espressif ESP32-C6) ----------------------------------------------
ADC_MIN_USEFUL_MV = 1000.0      # Aufloesungsreserve am unteren Ende

# ===========================================================================
# Annahmen des Modells (keine Datenblattwerte), zentral in circuit.ASSUMPTIONS
# ===========================================================================
EN_INPUT_LEAK_UA = circuit.ASSUMPTIONS.get("en_input_leak_ua", 0.0)

# Datenblatt-Fakten zum ESP32-C6 (als Konstanten mit Quelle hart verdrahtet).
# Espressif ESP32-C6-Datenblatt: LP-/RTC-GPIOs sind GPIO0 bis GPIO7.
LP_GPIO_MIN, LP_GPIO_MAX = 0, 7
# Strapping-Pins: GPIO8/GPIO9 (Boot-Modus) und GPIO15 (JTAG-Quelle), dazu
# IO4/IO5 (nur SDIO-Strap, nicht boot-kritisch).
STRAPPING_GPIOS = frozenset({4, 5, 8, 9, 15})
BOOT_CRITICAL_STRAPPING_GPIOS = frozenset({8, 9, 15})

# Modulpin der ESP32-C6-MINI-1 fuer die Erweiterungspins (aus dem Modulsymbol
# bzw. dem Espressif-Datenblatt, Pin-Tabelle).  IO22 ist seit 15.09.2026 keine
# Reserve mehr, sondern PUMP2_EN (Sauerstoffpumpe) -> kein Eintrag.
EXT_IO_PIN = {
    0: 12,   # ADC1_CH0, J2 Feuchtesensor
    4: 9,    # ADC1_CH4, J7 Lichtsensor
    5: 10,   # ADC1_CH5, J9 Reserve-Analog
    8: 22,   # Strapping (Boot-Modus), nur Pull-up
    9: 23,   # Strapping (Boot-Modus), Boot-Taster
    15: 20,  # Strapping (JTAG-Quelle); J10, Serien-R schuetzt den Pin
    18: 24,  # I2C SDA
    19: 25,  # I2C SCL
    20: 26,  # Load-Switch-Eingang (WPU beim Reset)
    21: 27,  # J13 Reserve-Digital
    23: 29,  # J15 Reserve-Digital
    16: 31,  # TXD0
    17: 30,  # RXD0
}

# 3-polige Sensor-/Reserve-Stecker mit der Ordnung GND-VCC-SIG.
# J14 ist seit 15.09.2026 entfernt (IO22 = PUMP2_EN/J16).
DREIPOL_STECKER = {
    "J2": ("SENSOR_RAW", "SENSOR_PWR"),
    "J7": ("LIGHT_RAW", "SENSOR_PWR"),
    "J9": ("SPARE_AIN_RAW", "VCC_EXT"),
    "J10": ("SPARE_IO15_RAW", "VCC_EXT"),
    "J11": ("SPARE_IO16", "VCC_EXT"),
    "J12": ("SPARE_IO17", "VCC_EXT"),
    "J13": ("SPARE_IO21_RAW", "VCC_EXT"),
    "J15": ("SPARE_IO23_RAW", "VCC_EXT"),
}

# 4-poliger I2C-Stecker J8: GND-VCC-SDA-SCL (VCC innen, wie Qwiic/STEMMA).
I2C_STECKER = "J8"

# Signaleingang am Stecker -> (Stecker, Signalpin, Serien-R, Steckernetz,
# MCU-Netz, erwartete IO-Nummer).  J14 entfaellt (15.09.2026).
SERIEN_EINGAENGE = (
    ("J2", "3", "R6", "SENSOR_RAW", "SENSOR_AOUT", 0),
    ("J7", "3", "R_LIGHT_S", "LIGHT_RAW", "LIGHT_AOUT", 4),
    ("J9", "3", "R_SPARE_AIN", "SPARE_AIN_RAW", "SPARE_AIN", 5),
    ("J10", "3", "R_SPARE_IO15", "SPARE_IO15_RAW", "SPARE_IO15", 15),
    ("J11", "3", "R_SPARE_IO16", "SPARE_IO16", "UART_TX", 16),
    ("J12", "3", "R_SPARE_IO17", "SPARE_IO17", "UART_RX", 17),
    ("J13", "3", "R_SPARE_IO21", "SPARE_IO21_RAW", "SPARE_IO21", 21),
    ("J15", "3", "R_SPARE_IO23", "SPARE_IO23_RAW", "SPARE_IO23", 23),
    ("J8", "3", "R_SDA_S", "SDA", "SDA_MCU", 18),
    ("J8", "4", "R_SCL_S", "SCL", "SCL_MCU", 19),
)

# IO20 soll beim Reset einen internen Weak-Pull-up haben (Espressif
# ESP32-C6-Datenblatt, Abschnitt Strapping/Reset).
IO20_WPU_AT_RESET = True

# Typische Flussspannung der 0805-LEDs je LCSC-Code (Datenblattwerte).
LED_VF_BY_LCSC = {
    "C84256": 2.0,    # NATIONSTAR NCD0805R1, rot, 615-630 nm
    "C2297": 2.85,    # KENTO KT-0805G, gruen, 525 nm (InGaN)
}

# Aktive Bauteile auf dem VBAT-Netz mit ihrer Datenblatt-Eingangsspannung
# (V_IN,max).  Fehlt ein Bauteil hier und ist es kein zugelassenes Passiv, ist
# es ein harter Fehler -- genau die ME6211-Lektion (V_IN,max 6,0 V, Review §5
# Befund 4).
VBAT_IC_VIN_MAX = {
    "U_CHG": (IP2326_VIN_MAX_V, "IP2326 S. 3: Eingang 4,5-9,5 V (VOUT erzeugt 8,4 V)"),
    "U_BUCK5": (BUCK5_VIN_MAX_V, "SY8113B S. 1: Eingang 4,5-18 V"),
    "U_BUCK3": (BUCK3_VIN_MAX_V, "AP63203 DS41326: Eingang 3,8-32 V"),
}
# Passive/steckbare VBAT-Teilnehmer (Widerstaende, Kondensatoren, Stecker, TP).
# R_PROT_VDD ist der neue 330-Ohm-VDD-Vorwiderstand des Schutz-IC (U_PROT) nach
# VBAT. Ein 0805-Dickschichtwiderstand hat eine Nenn-Gleichspannungs-
# festigkeit von >= 50 V (typ. 150 V bei den ueblichen 0805-Typen, z. B.
# Yageo RC0805: V_working 150 V) und liegt damit weit ueber den 8,4 V des
# 2S-Packs -- zugelassen (schaltplan §3.3: R_PROT_VDD 330 Ohm, HY2120-Datenblatt
# 100..470 Ohm Typ 330; JLC-Basic C17630).
# F1 sitzt in der Pack-Plus-Leitung (PACK_PLUS -> F1 -> VBAT): Littelfuse
# 0452005.MRL (452-Serie, 2410) ist mit 125 V AC/DC weit ueber den 8,4 V des
# 2S-Packs zugelassen (Datenblatt Littelfuse 452-Serie; LCSC C66503).
VBAT_PASSIV = frozenset({
    "C_CHG_OUT", "J1", "TP4", "C_B5_IN", "C_B5_IN_HF",
    "C_B3_IN", "C_B3_IN_HF", "R3a", "R_SENSE_TOP", "R_PROT_VDD", "F1",
})

# Woertliche Belegstellen der SYSTEM-Zahlen (Datei -> Pfad).
_SYSTEM_FILES = {
    "schaltplan_v1.md": circuit.SCHEMATIC_PATH,
    "bom_entscheidung.md": circuit.BOM_DECISION_PATH,
}


def _f(value, decimals, unit=""):
    text = ("%%.%df" % decimals) % value
    return text.replace(".", ",") + ((" " + unit) if unit else "")


def _err(designator):
    return circuit.CircuitError("fehlender Designator: %s" % designator)


def led_vf(designator):
    """Typische Flussspannung einer LED aus ihrem LCSC-Code in schaltplan_v1.md.

    Unbekannte Codes sind ein harter Fehler, damit nicht stillschweigend eine
    falsche Flussspannung angenommen wird.
    """
    lcsc = circuit.part(designator).get("lcsc")
    if not lcsc:
        raise circuit.CircuitError(
            "kein LCSC-Code fuer %s in schaltplan_v1.md" % designator)
    if lcsc not in LED_VF_BY_LCSC:
        raise circuit.CircuitError(
            "unbekannter LCSC-Code %r fuer %s: Flussspannung in "
            "LED_VF_BY_LCSC ergaenzen" % (lcsc, designator))
    return LED_VF_BY_LCSC[lcsc]


def _nets_of(designator):
    """Netz -> Pin fuer alle Pins eines Bauteils aus der Netzliste."""
    result = {}
    for net, nodes in circuit.load_netlist().items():
        for comp, pin in nodes:
            if comp == designator:
                result.setdefault(net, pin)
    return result


def _pins_of(designator):
    """Pin -> Netz fuer alle Pins eines Bauteils aus der Netzliste.

    Pin-Nummern werden auf die fuehrende Ziffer reduziert ("3 Drain" -> "3",
    "24 IO18" -> "24"), damit Stecker- und Halbleiterpins vergleichbar sind.
    Nicht-numerische Pins (z. B. "Anode") bleiben als Name erhalten.
    """
    result = {}
    for net, nodes in circuit.load_netlist().items():
        for comp, pin in nodes:
            if comp != designator:
                continue
            m = re.match(r"\s*([0-9]+)\b", pin)
            key = m.group(1) if m else pin.strip()
            result.setdefault(key, net)
    return result


def _u1_pin_on_net(net):
    """Modulpin-Nummer des U1-Pins auf einem Netz, sonst Fehler."""
    for comp, pin in circuit.load_netlist().get(net, []):
        if comp == "U1":
            m = re.match(r"\s*([0-9]+)\b", pin.strip())
            if m:
                return int(m.group(1)), pin.strip()
    raise circuit.CircuitError("kein U1-Pin auf Netz %s" % net)


def _btn_net():
    """Name des Tasternetzes, auf dem R_BTN und C_BTN gemeinsam liegen."""
    r_nets = _nets_of("R_BTN")
    c_nets = _nets_of("C_BTN")
    shared = sorted(set(r_nets) & set(c_nets))
    if len(shared) != 1:
        raise circuit.CircuitError(
            "Tasternetz nicht eindeutig: R_BTN auf %s, C_BTN auf %s"
            % (sorted(r_nets), sorted(c_nets)))
    return shared[0]


def _u1_io_on_net(net):
    """(IO-Nummer, roher Pinname) des U1-Pins auf einem Netz, sonst Fehler."""
    for comp, pin in circuit.load_netlist().get(net, []):
        if comp == "U1":
            m = re.search(r"IO([0-9]+)", pin)
            if m:
                return int(m.group(1)), pin.strip()
    raise circuit.CircuitError("kein U1-IO-Pin auf Netz %s" % net)


def _light_dark_counts(r_load):
    """ADC-Counts im Dunkeln aus ICEO_max am Lastwiderstand."""
    v_dark = circuit.LIGHT_SENS_DARK_UA * 1e-6 * r_load
    return v_dark / (circuit.ADC_VREF_MV_ATTEN12 / 1000.0) * circuit.ADC_COUNTS_12BIT


def _light_counts_at(lux, r_load):
    """ADC-Counts bei einer Beleuchtungsstaerke, gesaettigt auf den Vollausschlag."""
    vref = circuit.ADC_VREF_MV_ATTEN12 / 1000.0
    i = circuit.LIGHT_SENS_UA_REF * 1e-6 * (lux / circuit.LIGHT_SENS_LUX_REF)
    return min(i * r_load, vref) / vref * circuit.ADC_COUNTS_12BIT


def _uvlo_trip(sys=None):
    """Ausloesespannung des TPS3839 am 1:2-Teiler (Packspannung)."""
    sys = sys or circuit.load_system()
    r3a = circuit.parse_ohm(circuit.part("R3a")["value"])
    r3b = circuit.parse_ohm(circuit.part("R3b")["value"])
    iq = sys["iq_watchdog_ua"] * 1e-6
    return TPS3839_VIT_NOM_V * (1.0 + r3a / r3b) + iq * r3a


# ===========================================================================
# Neue Pruefungen (2S)
# ===========================================================================

def check_ladestrom_ip2326():
    """IP2326: ICHG = 90000/R_ISET, Grenze 1,5 A und 1 C des Packs."""
    r_iset = circuit.parse_ohm(circuit.part("R_ISET")["value"])
    sys = circuit.load_system()
    i_chg = IP2326_ICHG_K / r_iset
    c_rate = sys["pack_capacity_mah"] / 1000.0
    ok = i_chg <= IP2326_ICHG_MAX_A and i_chg <= c_rate
    return CheckResult(
        "Ladestrom IP2326", ok,
        "%s (R_ISET %s)" % (_f(i_chg, 2, "A"), _f(r_iset / 1000.0, 0, "kΩ")),
        "<= 1,5 A und <= 1 C = %s" % _f(c_rate, 2, "A"),
        "IP2326-Datenblatt V1.11: ICHG = 90000/R_ISET[Ohm] (S. 11); "
        "Grenze 1,5 A (§7, S. 4); ISET darf nicht offen bleiben (§4); "
        "Li-Ion erlaubt 1 C (Review §4.1)")


def check_ladeschluss_2s():
    """Ladeschluss = 2 x 4,2 V, VSET/CON_SEL offen, keine 8V8-Variante im BOM."""
    v_target = 2.0 * IP2326_CELL_MAX_V
    within = abs(v_target - IP2326_VSET_OPEN_V) <= IP2326_VSET_TOL_V
    bom = circuit.BOM_PATH.read_text(encoding="utf-8") if circuit.BOM_PATH.exists() else ""
    no_8v8 = "8V8" not in bom and "8v8" not in bom
    # Pin 3 = VSET (offen ⇒ 8,4 V), Pin 10 = CON_SEL (offen ⇒ 2S).
    offen = {}
    for pin_no in ("3", "10"):
        offen[pin_no] = all(
            not (comp == "U_CHG" and re.match(r"\s*%s\b" % pin_no, pin))
            for _net, nodes in circuit.load_netlist().items()
            for comp, pin in nodes)
    ok = within and no_8v8 and all(offen.values())
    return CheckResult(
        "Ladeschluss 2S", ok,
        "%s (2 x %s), VSET %s, CON_SEL %s, 8V8 im BOM %s"
        % (_f(v_target, 2, "V"), _f(IP2326_CELL_MAX_V, 1, "V"),
           "offen" if offen["3"] else "VERDRAHTET",
           "offen" if offen["10"] else "VERDRAHTET",
           "nein" if no_8v8 else "JA -> FEHLER"),
        "8,4 V +-0,1 V, VSET/CON_SEL offen, kein IP2326_8V8",
        "IP2326 S. 4/S. 5: VSET offen ⇒ 8,4 V (8,3-8,5 V) = 4,2 V/Zelle, "
        "CON_SEL offen ⇒ 2S (S. 8); IP2326_8V8 waere 8,8 V (4,4 V/Zelle) "
        "und fuer Li-Ion unzulaessig")


def check_ladeeingang_strom():
    """Eingangsstrom aus 5 V: Ladeleistung/eta plus Systemlast."""
    sys = circuit.load_system()
    r_iset = circuit.parse_ohm(circuit.part("R_ISET")["value"])
    i_chg = IP2326_ICHG_K / r_iset
    i_sys = sys["pump_i_nom_a"] + sys["o2_pump_i_a"]
    i_in = sys["pack_v_max"] * i_chg / (IP2326_EFF * sys["supply_v"]) + i_sys
    ok = i_in <= sys["supply_i_a"]
    return CheckResult(
        "Ladeeingangsstrom", ok,
        "%s (Ladung %s + System %s)"
        % (_f(i_in, 2, "A"),
           _f(sys["pack_v_max"] * i_chg / (IP2326_EFF * sys["supply_v"]), 2, "A"),
           _f(i_sys, 2, "A")),
        "<= %s (Netzteilannahme)" % _f(sys["supply_i_a"], 1, "A"),
        "IP2326 S. 1: eta 94 % (5 V->8 V/1 A); I_in = V_out*I_CHG/(eta*V_USB) "
        "+ Systemlast (beide Pumpen, schaltplan §6.1)")


def check_buck5_ausgang():
    """5-V-Buck SY8113B: V_out = 0,6 V x (1 + R_FB5_TOP/R_FB5_BOT)."""
    v = circuit.rail_5v()
    sys = circuit.load_system()
    nominal = sys["pump_v"]
    ok = abs(v - nominal) <= 0.05 * nominal
    return CheckResult(
        "5-V-Buck-Ausgang", ok,
        "%s (+-5 %% von %s)" % (_f(v, 3, "V"), _f(nominal, 1, "V")),
        "5,0 V +-5 %",
        "SY8113B-Datenblatt S. 1/S. 2: V_REF 0,6 V +-1,5 %, "
        "V_out = 0,6 x (1 + R_FB5_TOP/R_FB5_BOT); Pumpennennspannung 5 V")


def check_buck3_ausgang():
    """AP63203-Festspannungsversion: FB (Pin 1) direkt auf +3V3, kein Teiler.

    Geprueft wird beides: der Ausgangswert liegt im Modulfenster, UND FB ist
    wirklich direkt am Ausgang (nicht ueber einen Teiler), UND es existiert
    kein Teilerbauteil R_FB3_TOP/R_FB3_BOT und kein Netz FB_3V3 mehr.
    """
    v = circuit.rail_3v3()
    fb_net = _pin_net("U_BUCK3", "1")
    fb_direct = fb_net == "+3V3"
    rest_teiler = [d for d in circuit.parts() if d.startswith("R_FB3")]
    netz_fb = "FB_3V3" in circuit.load_netlist()
    spannung_ok = MODULE_VDD33_MIN_V <= v <= MODULE_VDD33_MAX_V
    ok = spannung_ok and fb_direct and not rest_teiler and not netz_fb
    return CheckResult(
        "3,3-V-Buck-Ausgang", ok,
        "%s (FB Pin 1 auf %s %s, Teiler %s, Netz FB_3V3 %s)"
        % (_f(v, 3, "V"), fb_net, "OK" if fb_direct else "FEHLER",
           ", ".join(rest_teiler) or "keiner",
           "vorhanden -> FEHLER" if netz_fb else "entfallen"),
        "3,0 V bis 3,6 V (Modul); FB direkt auf +3V3, kein Teiler",
        "AP63203-Datenblatt DS41326: Festspannungsversion, VFB 3,27/3,30/3,33 V "
        "bzw. 'AP63203 ... fixed output voltages of 3.3V'; Fig. 21 fuehrt FB "
        "direkt auf den Ausgang. Der frueher geprüfte Teiler R_FB3_TOP/BOT ist "
        "entfallen (Review 16.09.2026); Espressif ESP32-C6-MINI-1: "
        "V_DD33 3,0-3,6 V")


def check_buck5_induktivitaet():
    """Rippelstrom und Spitzenstrom des 5-V-Bucks bei Last bis 3 A."""
    l = circuit.parse_henry(circuit.part("L_BUCK5")["desc"])
    isat = circuit.parse_ampere(circuit.part("L_BUCK5")["value"])
    sys = circuit.load_system()
    v_out = circuit.rail_5v()
    i_last = sys["pump_i_inrush_a"]
    ok = i_last <= BUCK5_IOUT_MAX_A
    teile = []
    for v_in in (sys["pack_v_max"], _uvlo_trip(sys)):
        d = v_out / v_in
        di = (v_in - v_out) * d / (l * BUCK5_FSW_HZ)
        i_peak = i_last + di / 2.0
        teile.append("Vin %s: dI %s, I_peak %s"
                     % (_f(v_in, 2, "V"), _f(di, 2, "A"), _f(i_peak, 2, "A")))
        ok = ok and i_peak < isat
    return CheckResult(
        "5-V-Buck-Induktivitaet", ok,
        "%s (I_Last %s, Isat %s); %s"
        % (_f(l * 1e6, 1, "µH"), _f(i_last, 1, "A"), _f(isat, 1, "A"),
           "; ".join(teile)),
        "I_peak < Isat 4,0 A und I_Last <= 3 A",
        "PRS6045-Datenblatt: L_BUCK5 4,7 µH, Isat 4,0 A; SY8113B S. 1: 3 A, "
        "500 kHz; dI = (Vin-Vout)*D/(L*f) mit D = Vout/Vin; "
        "I_Last = Pumpenanlauf 3 A (bom §4c)")


def check_buck3_induktivitaet():
    """Rippelstrom und Spitzenstrom des 3,3-V-Bucks bei 1,1 MHz."""
    l = circuit.parse_henry(circuit.part("L_BUCK3")["desc"])
    isat = circuit.parse_ampere(circuit.part("L_BUCK3")["value"])
    sys = circuit.load_system()
    v_out = circuit.rail_3v3()
    i_last = sys["module_tx_peak_ma"] / 1000.0
    ok = True
    teile = []
    for v_in in (sys["pack_v_max"], _uvlo_trip(sys)):
        d = v_out / v_in
        di = (v_in - v_out) * d / (l * BUCK3_FSW_HZ)
        i_peak = i_last + di / 2.0
        teile.append("Vin %s: dI %s, I_peak %s"
                     % (_f(v_in, 2, "V"), _f(di, 2, "A"), _f(i_peak, 2, "A")))
        ok = ok and i_peak < isat
    return CheckResult(
        "3,3-V-Buck-Induktivitaet", ok,
        "%s (I_Last TX-Peak %s, Isat %s); %s"
        % (_f(l * 1e6, 1, "µH"), _f(i_last, 3, "A"), _f(isat, 1, "A"),
           "; ".join(teile)),
        "I_peak < Isat 4,0 A",
        "PRS6045-Datenblatt: L_BUCK3 4,7 µH, Isat 4,0 A; AP63203 DS41326: "
        "2 A, 1,1 MHz; I_Last = Modul-TX-Peak 382 mA (Espressif Tab. 6-4)")


def check_uvlo_schwelle():
    """TPS3839-Ausloesung: V_trip = V_IT x (1 + R3a/R3b) + Iq x R3a."""
    sys = circuit.load_system()
    r3a = circuit.parse_ohm(circuit.part("R3a")["value"])
    v_trip = _uvlo_trip(sys)
    ok = WATCHDOG_TRIP_MIN_V <= v_trip <= WATCHDOG_TRIP_MAX_V
    return CheckResult(
        "UVLO-Schwelle", ok,
        "%s (V_IT %s, R3a %s, Iq %s)"
        % (_f(v_trip, 3, "V"), _f(TPS3839_VIT_NOM_V, 2, "V"),
           _f(r3a / 1000.0, 0, "kΩ"), _f(sys["iq_watchdog_ua"], 2, "µA")),
        "6,0 V bis 6,6 V Pack (2 x 3,0..3,3 V)",
        "TPS3839 S. 7: V_IT 3,003-3,126 V, Hysterese 31 mV; "
        "V_trip = V_IT x (1 + R3a/R3b) + Iq x R3a (Teiler 51 k/51 k, "
        "Iq typ. 0,15 µA bzw. max. 0,5 µA)")
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

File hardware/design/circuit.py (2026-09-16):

"""Schaltplan-Modell fuer den Smart Grow Topf V1 (Stand 2S-Umbau, 16.09.2026).

Liest die Verbindungen aus ``schaltplan_v1_netzliste.csv`` und die Bauteilwerte
aus ``schaltplan_v1.md``.  Bauteilwerte kommen ausschliesslich ueber
:func:`part` aus den Tabellen §3.1-§3.4.  Systemkenngroessen (Pumpe, Pack,
Modul, ADC) stehen in dem klar markierten :data:`SYSTEM`-Block; jede Zahl
traegt eine woertliche Belegstelle, die :func:`check_system_quellen` in
``checks.py`` gegen die Dokumente prueft.

Nur Standardbibliothek, Python 3.9-kompatibel.
"""
from __future__ import annotations

import csv
import re
from collections import namedtuple
from functools import lru_cache
from pathlib import Path

BASE_DIR = Path(__file__).resolve().parent
HARDWARE_DIR = BASE_DIR.parent
NETLIST_PATH = HARDWARE_DIR / "schaltplan_v1_netzliste.csv"
SCHEMATIC_PATH = HARDWARE_DIR / "schaltplan_v1.md"
BOM_PATH = HARDWARE_DIR / "pcba_bom_jlc.csv"
BOM_DECISION_PATH = HARDWARE_DIR / "bom_entscheidung.md"

# Einpolige Elemente (Testpunkte), die nur auf einem Netz liegen duerfen.
ONE_PIN_OK_PREFIX = ("TP",)

# ---------------------------------------------------------------------------
# DATENBLATTGRENZEN, die das Modell selbst braucht (jede mit Quelle).
# ---------------------------------------------------------------------------
VREF_BUCK5 = 0.6   # SY8113B (Silergy) Datenblatt AN_SY8113B S.1/S.2: V_REF 0,6 V
# AP63203 (Diodes) ist die FESTSPANNUNGSVERSION (AP63203 = 3,3 V, AP63205 = 5 V,
# Datenblatt DS41326 Fig. 21: FB direkt auf den Ausgang).  Der frueher hier
# gerechnete Teiler R_FB3_TOP/R_FB3_BOT existiert seit dem Review 16.09.2026
# nicht mehr -- V_OUT wird nicht mehr aus Widerstaenden, sondern als
# Datenblatt-Festwert angenommen (3,27/3,30/3,33 V).
VOUT_BUCK3_FIXED = 3.30

# ---------------------------------------------------------------------------
# SYSTEM - Systemkenngroessen aus den Projektdokumenten.
#
# Jeder Eintrag traegt seinen Wert, die Einheit, die Datei und ein woertliches
# Textfragment (Beleg).  check_system_quellen() weist nach, dass der Beleg
# wirklich in der Datei steht.  Das Dokument ist die einzige Quelle dieser
# Zahlen; im uebrigen Code sind sie ausschliesslich an dieser Stelle erlaubt.
# ---------------------------------------------------------------------------
SystemEntry = namedtuple("SystemEntry", "key wert einheit datei beleg")

SYSTEM = (
    # Pack (2S)
    SystemEntry("pack_v_min", 6.0, "V", "schaltplan_v1.md", "6,0\u20138,4 V"),
    SystemEntry("pack_v_max", 8.4, "V", "schaltplan_v1.md", "8,4 V"),
    SystemEntry("pack_capacity_mah", 2000.0, "mAh", "bom_entscheidung.md", "2000 mAh"),
    SystemEntry("cell_v_nom", 3.7, "V", "bom_entscheidung.md", "3,7 V"),
    SystemEntry("cell_firmware_stop_v", 3.4, "V", "bom_entscheidung.md", "3,4 V Pumpstopp"),
    SystemEntry("cell_pcm_v", 2.5, "V", "bom_entscheidung.md", "2,5 V"),
    # Pumpen
    SystemEntry("pump_v", 5.0, "V", "bom_entscheidung.md", "DC 5 V"),
    SystemEntry("pump_i_nom_a", 0.4, "A", "bom_entscheidung.md", "0,4 A"),
    SystemEntry("pump_i_inrush_a", 3.0, "A", "bom_entscheidung.md", "Anlaufstrom 3 A"),
    SystemEntry("o2_pump_i_a", 0.2, "A", "bom_entscheidung.md", "0,20 A"),
    SystemEntry("pump_flow_ml_min", 150.0, "ml/min", "bom_entscheidung.md", "150 ml/min"),
    SystemEntry("dose_ml", 300.0, "ml", "bom_entscheidung.md", "300 ml"),
    SystemEntry("pwm_hz", 20000.0, "Hz", "bom_entscheidung.md", "20 kHz"),
    # Modul (ESP32-C6-MINI-1)
    SystemEntry("module_tx_peak_ma", 382.0, "mA", "schaltplan_v1.md", "382 mA"),
    SystemEntry("module_sleep_ua", 7.0, "\u00b5A", "schaltplan_v1.md", "7 \u00b5A"),
    # Ruhestrom der Bausteine (aus den Datenblaettern, im Dokument belegt)
    SystemEntry("iq_buck5_ua", 100.0, "\u00b5A", "schaltplan_v1.md", "100 \u00b5A"),
    SystemEntry("iq_buck3_ua", 22.0, "\u00b5A", "schaltplan_v1.md", "22 \u00b5A"),
    SystemEntry("iq_watchdog_ua", 0.15, "\u00b5A", "schaltplan_v1.md", "0,15 \u00b5A"),
    # Netzteilannahme
    SystemEntry("supply_v", 5.0, "V", "schaltplan_v1.md", "USB-C 5 V"),
    SystemEntry("supply_i_a", 2.5, "A", "schaltplan_v1.md", "\u2265 2,5 A"),
    # ADC (Espressif ESP32-C6, ADC_ATTEN_DB_12)
    SystemEntry("adc_vref_mv", 3300.0, "mV", "schaltplan_v1.md", "3300 mV"),
    SystemEntry("adc_bits", 12.0, "", "schaltplan_v1.md", "12 Bit"),
)

# ---------------------------------------------------------------------------
# ANNAHMEN - bewusst keine Datenblattwerte, sondern Modellannahmen.  Sie sind
# hier zentral dokumentiert und werden in der Ausgabe als Annahme genannt.
# ---------------------------------------------------------------------------
ASSUMPTIONS = {
    "r_bat_ohm": 0.15,        # Innenwiderstand eines 2S-Rundzellenpacks, typ. 2 x 60-100 mOhm
    "cc_frac": 0.8,           # Anteil der Ladung in der CC-Phase (Rest CV)
    "cv_i_frac": 0.4,         # mittlerer Ladestrom in der CV-Phase, bezogen auf ICHG
    "usable_frac": 0.8,       # nutzbarer Anteil der Packkapazitaet
    "en_input_leak_ua": 1.0,  # EN-Eingangsleckstrom des SY8113B, konservativ (Datenblatt nennt keinen Einzelwert)
}

# Datenblatt-Fakten zum Lichtsensor ALS-PT19-315C/L177/TR8 (LCSC C146233).
# Der Sensor haengt extern an J7 und ist KEINE BOM-/PCBA-Position.
LIGHT_SENS_LUX_REF = 100.0        # Bezugsbeleuchtungsstaerke des Datenblatts
LIGHT_SENS_UA_REF = 15.0          # Kollektorstrom typisch bei 100 lx [µA]
LIGHT_SENS_DARK_UA = 0.1          # ICEO max. im Dunkeln [µA]
LIGHT_GROW_LUX = 10000.0          # typische LED-Growlampe am Canopy [lx]
ADC_VREF_MV_ATTEN12 = 3300.0      # ADC_ATTEN_DB_12 (ATTEN3): 0..3300 mV
ADC_COUNTS_12BIT = 4095.0         # 12-Bit-Vollausschlag
LIGHT_DARK_COUNTS = 200.0         # absoluter Notwert "dunkel" [ADC-Counts]
LIGHT_BRIGHT_COUNTS = 3000.0      # absoluter Notwert "hell" [ADC-Counts]
LIGHT_HYSTERESE_COUNTS = 300.0    # Mindestabstand dunkel/hell [ADC-Counts]

# SI-Praefixe in Basiseinheiten.
_SI_PREFIX = {
    "p": 1e-12,
    "n": 1e-9,
    "µ": 1e-6,
    "u": 1e-6,
    "m": 1e-3,
    "k": 1e3,
    "K": 1e3,
    "M": 1e6,
    "G": 1e9,
}

_NUM = r"([0-9]+(?:[.,][0-9]+)?)"
_PFX = r"([pnu\u00b5mMkKG]?)"


class CircuitError(Exception):
    """Fehler beim Laden oder Auswerten der Schaltplandaten."""


def _clean(text):
    """Entfernt Markdown-Zeichen und Leerraum aus einer Tabellenzelle."""
    return str(text).replace("`", "").replace("*", "").replace("~", "").strip()


def _to_float(text):
    """Wandelt '4,7' oder '4.7' in float um."""
    s = str(text).strip().replace(" ", "")
    if "," in s and "." not in s:
        s = s.replace(",", ".")
    elif "," in s and "." in s:
        s = s.replace(",", "")
    return float(s)


def _strip_multiplier(text):
    """Entfernt einen Mengen-Vorspann wie '2 × ' vor dem eigentlichen Wert."""
    return re.sub(r"^\s*[0-9]+\s*[\u00d7xX]\s*", "", text)


def _si(value):
    """Normalisiert auf 12 signifikante Stellen (vermeidet 1e-07-Ungenauigkeit)."""
    return float("%.12g" % value)
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

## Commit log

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2026-09-11 Gehaeuse-CAD (OpenSCAD, parametrisch): 9 druckbare Teile + Zusammenbau-Layout
    - params.scad: alle Masse zentral (O140, 278 mm, Tank 82/71, Luftspalt 30, Innentopf 132x150)
    - 9 Teile rendern unabhaengig mit Exit 0 (eigene Verifikation, CGAL, Simple: yes)
    - Aussenschale zweigeteilt fuer 220x220x250 Bauraum (Trennlinie z=90)
    - case/README.md: Teileliste, Druckparameter, Montage, dokumentierte Abweichungen
    - tools/oscad-render: headless WASM-Renderer (Cask ist Gatekeeper-deaktiviert)
    [case.scad, cover.scad, distribution_ring.scad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]
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2026-09-11 PCBA-Review: JLC-Verfuegbarkeit aller Bauteile (LCSC-Codes) + Review V1; blockierend: PCB 42mm > Kammer 40mm
    [pcba_bom_jlc.csv]
2026-09-11 Unterspannungsschutz V1: 4 Ebenen (FW 3,4V / MAX809 3,08V / Gate-Pulldown / Zell-PCM); MCP73831 hat keinen Entladeschutz (Datenblatt)
    [pcba_bom_jlc.csv]
2026-09-11 MCU-Umstellung: ESP32-C6-MINI-1 auf eigener PCB statt XIAO; Lader MCP73831, LDO ME6211 (TX-Peak 382mA), USB nativ; Antennen-Keepout 15mm als Geometrieauflage
    [pcba_bom_jlc.csv]
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2026-09-11 Review Schaltplan: 2 Fehler behoben (MAX809-Klemmstrom 3mA>1,2mA Spec; LED am Strapping-Pin MTMS), 5 Schwachstellen entschaerft, JLC-BOM resynchronisiert
    [pcba_bom_jlc.csv, schaltplan_v1_netzliste.csv]
2026-09-11 Review 2 Schaltplan: Netzlisten-Lint ergaenzt; 6 Netzlisten-Fehler behoben (R_PROG fehlte, R6 kurzgeschlossen, beide LED-Ketten, LDO-EN, UART) + Testpunkte
    [schaltplan_v1_netzliste.csv]
2026-09-11 Review 3-5: Querabgleich aller Dokumente; D4 (unsichere VBUS-Bruecke) aus der JLC-BOM entfernt, 11 veraltete Angaben korrigiert, 2 Pruefskripte ergaenzt
    [assembly.scad, modules.scad, params.scad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]
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2026-09-11 Externer Taster (J6 Lotpads an IO6, weckfaehig aus Deep-Sleep) + rote Tank-LED D5 (IO7): Schaltplan Abschnitt 7, Netzliste, BOM, 3 neue Pruefungen + Blink-Simulation, Mutationstest 19/19
    [pcba_bom_jlc.csv, schaltplan_v1_netzliste.csv]
2026-09-11 Status-LED D2 von rot auf gruen (C2297, Vf 2.85V) mit R4 220 Ohm; neue Pruefung LED-Headroom; Flussspannung je LED ueber LCSC-Code (unbekannt = harter Fehler); Mutationstest 20/20
    [pcba_bom_jlc.csv]
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2026-09-11 Schaltplan SmartGrowTopf_V1 in EasyEDA Pro aufgebaut (A2, 54 Bauteile, 30 Netze)
    Kompletter, reproduzierbarer Bau nach Design-Flow S0-S6 mit der easyeda-agent
    CLI. Quelle ist die unveraenderte Handnetzliste hardware/schaltplan_v1_netzliste.csv.
    Stand (Belege in hardware/easyeda/s5/FINAL_*):
    - Blatt A2 quer (594x420 mm), Titelblock-Freihaltezone ab x>=1636 / y<=198
    - 54 Bauteile, 163 Leitungssegmente, 30 Netze, 25 NC-Pins, 10 Modulgruppen
    - Netzlisten-Treue: 0 Abweichungen (Pin-fuer-Pin gegen raw/ir_numbered.json)
    - layout-lint 0 Ueberlappungen / 0 ausserhalb des Blatts, bridge-check 0 Bruecken
    0 verwaiste Baeume, DRC 0 fatal / 0 error / 1 warn, check 0 Fehler / 5 Warnungen
    - sch gate: fai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
    [build_autoconnect.py, build_ir.py, build_layout_input.py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]
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2026-09-13 Lichtsensor, GPIO-Erweiterung und Pinordnung GND-VCC-SIG; U1-Massepads einzeln verdrahtet
    Schaltplan aus der Netzliste neu aufgebaut (A2): 75 Bauteile, 45 Netze,
    213 Verbindungen, 12 Module. Neu: J7/R_LIGHT/R_LIGHT_S/C_LIGHT (Licht-Gate),
    J8/Q2 mit geschalteter VCC_EXT + I2C-Pull-ups, J9/J10 Reserve, TP7-TP11 als
    Loetpads fuer IO15/16/17/22/23. J2 und J7 jetzt GND-VCC-SIG (VCC mittig).
    U1-Pins 36-53 (Modulmasse) hingen in der Luft - Netzlisten-Sammelzeile
    aufgeloest, 18 Pads einzeln verdrahtet (NC-Pins 4/7/21/32-35 bleiben frei).
    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
    [pcba_bom_jlc.csv, schaltplan_v1_netzliste.csv]
2026-09-13 Rueckbau der GPIO-Erweiterung (J8/J9/J10/Q2/TP7-TP11); Lichtsensor und Pinordnung GND-VCC-SIG bleiben
    Am 13.09. hatte der Commit 466ad9b vier Dinge gebuendelt: Lichtsensor (J7), Pinordnung
    GND-VCC-SIG, einzeln verdrahtete U1-Massepads und die GPIO-Erweiterung. Auf Wunsch des
    Nutzers ist nur die Erweiterung wieder entfernt - J7 (R_LIGHT/R_LIGHT_S/C_LIGHT),
    GND-VCC-SIG (J2/J7) und die Massepads bleiben.
    Netzliste/JLC-BOM: 42 Zeilen entfernt (J8, J9, J10, Q2, R_SDA_S, R_SDA_PU, R_SCL_S,
    R_SCL_PU, R_GATE, R_SPARE_AIN, R_SPARE_IO, C_SPARE, TP7-TP11) -> 58 Bauteile, 32 Netze,
    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
    [pcba_bom_jlc.csv, schaltplan_v1_netzliste.csv]
2026-09-14 Erweiterung neu auf Steckpins (2,54-mm-Stiftleisten) + Blatt A1 neu aufgebaut
    Nutzerwunsch 14.09.2026: freie GPIOs und I2C zum Draufstecken herausfuehren, Pinordnung
    GND-VCC-SIG (VCC mittig), I2C als GND-VCC-SDA-SCL; auch der Lichtsensor J7 wird Stiftleiste.
    Design: 80 Bauteile, 50 Netze, 72 bestueckte Positionen. Neu: J8 (I2C 4-pol), J9-J15
    (je ein freies Signal: IO5/IO15/IO16/IO17/IO21/IO22/IO23, 3-pol GND-VCC-SIG), Q2
    (AO3401A) als Load-Switch fuer VCC_EXT mit Gate-Pull-up = aus beim Reset, 1 kOhm in jeder
    Signalleitung, I2C-Pull-ups an VCC_EXT (nicht +3V3), C_SPARE 100 nF an IO5.
    LCSC live geprueft: C2937625 (1x3 PZ254V-11-03P), C2691448 (1x4 PZ254V-11-04P), C15127.
    Pruefer: report.py 2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
    [pcba_bom_jlc.csv, schaltplan_v1_netzliste.csv]
2026-09-14 hardware/easyeda/README: Live-Stand und Restpunkte auf den A1-Neuaufbau gezogen
    Der Live-Bau ist neu aufgebaut (Blatt A1, 80 Bauteile / 50 Netze / 233 Verbindungen,
    pin-fuer-pin 0 Abweichungen, sch gate = pass, strict nur an missing-titleblock).
    Die Restpunktliste nannte noch den alten Zustand (nur ein Rahmen gezeichnet, 6 floating-pins,
    2 DRC-Warnungen) - jetzt: missing-titleblock (Host), sich beruehrende Blockrahmen,
    Faeecher-Richtung nur live bekannt, PCB bewusst noch nicht gezogen.
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2026-09-14 CAD-Vorlage: Einfuellstutzen am Tank, LST-Ankerloecher im Kragen, Kappe (OpenSCAD) — wird nach build123d portiert
    [assembly.scad, case.scad, fill_plug.scad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]
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2026-09-14 Gehaeuse-CAD vollstaendig auf build123d umgestellt: 8 Druckteile + Baugruppe ueber Joints, Kappe kollisionsfrei, LST-Lochbild korrigiert; OpenSCAD (case/) entfernt
    [assembly.scad, case.scad, cover.scad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]
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2026-09-14 CAD: STEP-Exporte versioniert (8 Teile, Baugruppe, Explosionsansicht)
    - cad/export/*.step (11 MB) ins Repo: echte CAD-Austauschdateien fuer
    Nachbearbeitung/Fremd-CAD, aendern sich nur bei Geometrieaenderungen
    - STL/3MF bleiben ignoriert (33 MB Meshes, aus cad/export_all.py reproduzierbar)
    - Exportstand passt zu den Skripten (alle cad/*.py aelter als die Exporte)
    [assembly.step, cover.step, distribution_ring.step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]
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2026-09-15 Stecker J1/J2/J4 auf aufrecht (Top-Entry) umgestellt — gehen jetzt nach oben raus
    Schaltplan (live in EasyEDA geaendert) + Repo nachgezogen:
    - J1 Akku: C54582899 (S2B-PH-SM4-TB, SMD liegend) -> C160352 (B2B-PH-SM4-TB, SMD aufrecht)
    - J2 Sensor: C157928 (S3B-XH-A, THT gewinkelt) -> C493416 (B3B-XH-A-BK, THT aufrecht)
    - J4 Pumpe: C157931 (S2B-XH-A, THT gewinkelt) -> C158012 (B2B-XH-A, THT aufrecht)
    Nebeneffekt: die aufrechten Typen haben deutlich mehr Lager (J4 203.889 statt 2, J2 19.594).
    Vorgehen im Editor: Pins getrennt, Bauteil geloescht, neu platziert, Designator + uniqueId
    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
    [pcba_bom_jlc.csv]
2026-09-15 Sauerstoffpumpe + 5V-Boost: zweiter Pumpenpfad, Schaltplan neu aufgebaut
    Zweiter, baugleicher Leistungspfad fuer eine Sauerstoffpumpe:
    - Q3 (AO3400A) mit R20 4,7k Gate-Serie, R21 47k Pulldown, Freilauf D7 (1N5819WS),
    UV-Klemmzweig D8 an RESET_UV, 100nF C16 an den Klemmen
    - Stecker J16 = JST-XH 2P aufrecht (C158012, gleicher Typ wie J4)
    - Steuersignal IO22 (vorher Reserve J14, entfaellt); Stecker J7+J9-J13,J15 bleiben Reserve
    5V fuer BEIDE Pumpen (vorher hing die Pumpe direkt an VBAT 3,0-4,2 V):
    - U8 MT3608 Boost, L1 22uH (YNR6045), D6 SS34, C13/C14 22uF, C15 100nF, R18 75k/R19 10k
    - Vout = 0.6V*(1+75/10) = 5,10 V; neue Netze +5V, SW_BOOST, FB_5V
    - J4 Pin 1 und D1-Kathode liegen jetzt an +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
    [pcba_bom_jlc.csv, schaltplan_v1_netzliste.csv]
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2026-09-15 Schaltplan von Grund auf neu aufgebaut (Generatorkette) — Sauerstoffpumpe + 5V-Boost
    Arbeitsweise nach User-Vorgabe: kein Flicken, kein manuelles Umplatzieren, keine selbst
    vergebenen Designatoren. Stattdessen die Projekt-Generatorkette:
    Netzliste -> build_ir.py -> plan_layout.py -> build_autoconnect.py -> live
    clear -> place_all.sh -> Rahmen -> Gruppen -> autoconnect je Modul -> NC -> Diff -> gate.
    Offline-Kette auf den neuen Stand gezogen:
    - hardware/schaltplan_v1_netzliste.csv: bereinigt und erweitert (meine Ergaenzung von heute
    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
    [schaltplan_v1_netzliste.csv]
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2026-09-15 Review-Befunde abgearbeitet: 2 Netzfehler, BOM konsolidiert, Textbeschreibung korrigiert
    Verifizierte Fehler aus dem externen Review — alle gegen ir_numbered.json geprueft:
    1) ECHTE NETZFEHLER (Schaltung), korrigiert in der Handnetzliste:
    - C11 lag zwischen PUMP_N und VBAT statt ueber den Motorklemmen -> jetzt +5V
    (seit die Pumpe an +5V haengt, koppelte C11 Stoerungen in die Akkuschiene ein)
    - C20 lag zwischen PUMP2_N und GND statt ueber der Sauerstoffpumpe -> jetzt +5V
    Folge: build_ir.py neu, check_ir_netlist = 0 Abweichungen.
    2) FERTIGUNGS-BOM WAR INKONSISTENT (gravierend): funktionale/verrutschte
    Bezeichner (C1a, C_BTN, R_GATE) und falsche Zuordnungen — R20 (SCL-Pul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
    [pcba_bom_jlc.csv, schaltplan_v1_netzliste.csv]
2026-09-15 Review-Aenderungen im Schaltplan umgesetzt (offline, ohne EasyEDA)
    Umgesetzt (fachlich fuer richtig befunden):
    1) Klemmzweig vom Gate entkoppelt: D3/D8 hingen direkt am Gate, weshalb der Gate-
    Serienwiderstand auf 4,7 kOhm hochgesetzt werden musste (Klemmstrom in den MAX809).
    Jetzt: eigene Serienwiderstaende R35/R36 (10 k, neu) im Klemmzweig, Gate-Serie
    R1/R33 auf 1 kOhm -> Low-Pegel Reserve fuer PWM, Klemmstrom 0,30 mA (Spec 1,2 mA).
    2) Boost-EN (U8 Pin 4) haengt jetzt an RESET_UV mit R37 47 kOhm Pull-up nach VBAT
    statt fest an VBAT -> die 5-V-Schiene schaltet bei Unterspannung wirklich ab.
    Die Gateklemmung bleibt, weil der MT3608 ueber L1/D6 einen Pfad zum Ausgang hat.
    3) I2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
    [pcba_bom_jlc.csv, schaltplan_v1_netzliste.csv]
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2026-09-15 Live-Neuaufbau mit Review-Revision: 96 Bauteile, 56 Netze, 268 Verbindungen, 0 Abweichungen
    Kette komplett gefahren (diesmal mit verbundenem Fenster):
    - clear (93 Bauteile, 262 Draehte, 13 Rahmen, 13 Texte), place_all 96/96 FAIL=0
    - 13 Rahmen + 13 Titel, 13 Gruppen, autoconnect je Modul
    - 7 transiente connector-Timeouts (C10:2, C14:2, C15:2, C16:2, Q1:2, J2:1, R16:1) per
    Retry-Spec nachgezogen -> Pin-fuer-Pin-Diff gegen die Ziel-IR: 0 Abweichungen
    - 8 NC-Marker, gate: layout-lint pass (0/0), check pass, bridge-check pass (0 Waisen),
    drc pass; clusters: 1 Overlap + 1 knapp ausserhalb (Layout, Nutzer macht das selbst)
    - sch save, Blattbild exportiert
    Dokumentiert in hardware/easyeda/READM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
2026-09-16 Schaltplan auf 2S umgebaut: IP2326-Boost-Lader, 5-V- und 3,3-V-Buck statt Boost/LDO, TPS3839-Waechter, ADC-Teiler 1:3,94; Klemmzweig-Bug behoben, Pruefer fuer L* geeicht, Review + BOM regeneriert
    [pcba_bom_jlc.csv, schaltplan_v1_netzliste.csv]
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2026-09-16 Design-Pruefsuite auf 2S umgestellt (37 Pruefungen, exit 0) + Mutationstest 10/10; ADC-Teiler-Angaben in Kap.1/2.2/13 auf 1:3,94 (200k/68k) korrigiert; R3a/R3b als getrennte Zeilen fuer den Verhaeltn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
    [checks.py, circuit.py, report.py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]
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2026-09-16 Review-Fixes lokal: AP63203-FB direkt (Festspannungsversion), wirkungslosen Gate-Klemmzweig entfernt, UV-Teiler 51k/51k, Sensor-Lastschalter Q_SENS, Sicherung F1 5A, Akku-NTC an J18 mit 82k-Parallelw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
    [pcba_bom_jlc.csv, schaltplan_v1_netzliste.csv]
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2026-09-18 Platinengroesse korrigiert und auf 2-Lagen/einseitig umgestellt
    Rechenfehler behoben: die Belegungsdichte war ueber die volle Boardflaeche
    definiert (so wie am Referenzboard gemessen), zusaetzlich war ein 2,5-mm-Rand
    aufgeschlagen worden - doppelt gezaehlt, die Laengen waren dadurch 15-20 % zu gross.
    Jetzt konsistent: Boardflaeche = Summe / Dichte, keine Randterme.
    Ergebnis bei 54 mm Breite (alles auf einer Seite): 75 mm bei Referenzdichte 42,7 %,
    80 mm bei 40 %, 92 mm bei 35 %. Empfehlung fuer JLCPCB (2 Lagen, Bestueckung nur oben,
    GND-Flaeche unten): 54 x 90 mm = 35,6 % Belegung, 96 von 108 mm Kammerlaenge.
    Variante 4 Lagen/zweiseitig waere 54 x 75 mm. Kammerlaenge korrigiert: 108 mm uebe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
